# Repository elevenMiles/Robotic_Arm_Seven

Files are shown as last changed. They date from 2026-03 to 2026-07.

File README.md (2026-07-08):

---
# Supported by

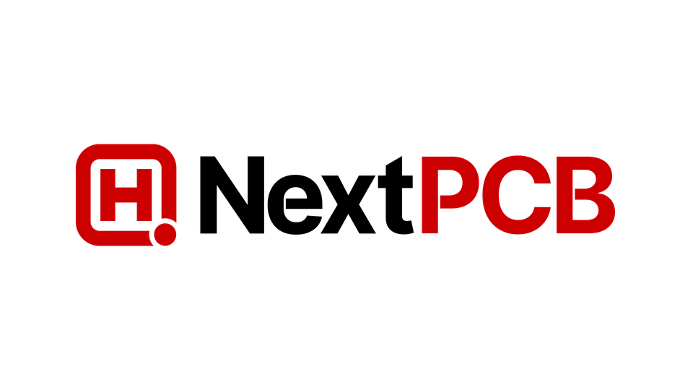
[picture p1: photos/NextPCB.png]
NextPCB


> Thanks to **NextPCB** for sponsoring this project with a financial grant – they're my first sponsor! If you ever need PCB or PCBA services, check them out using the link.
> -> https://www.nextpcb.com/?code=eleven

---

# Seven — 3-DOF Arduino Robotic Arm

> **⚠️ Safety Warning:** This project features a custom power supply setup. Please proceed at your own risk. I am not responsible for any damage to your components, your board, or yourself. Work carefully, and stay safe.

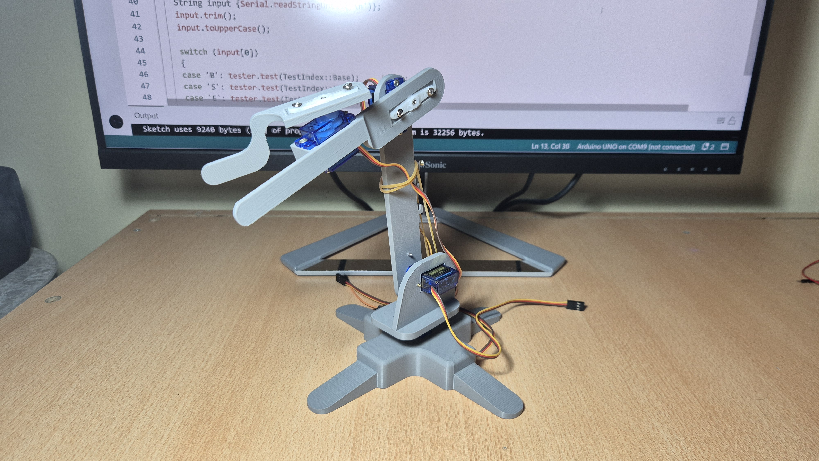
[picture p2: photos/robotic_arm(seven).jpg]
Seven Robotic Arm


A 3-DOF (Degrees of Freedom) robotic arm built with 3D-printed parts and SG90 servo motors, controlled via an Arduino Uno over serial communication. Seven supports **manual joint control**, **inverse kinematics**, **gripper control**, **waypoint list programming**, and **external software integration** via a handshake protocol.

---
Seven Robotic Arm Demo
---

## Assembly Guide

The assembly guide YouTube video is here: https://youtu.be/ZC04lUFtJYI?si=HDjUfc8iGIEtEkAY

---

## Table of Contents

- [Features](#features)
- [Hardware Requirements](#hardware-requirements)
- [3D Printing](#3d-printing)
- [Wiring & Circuit](#wiring--circuit)
- [Testing](#testing)
- [Software Setup](#software-setup)
- [Command Reference](#command-reference)
- [Calibration](#calibration)
- [Coordinate System](#coordinate-system)
- [Waypoint Lists](#waypoint-lists)
- [External Software Integration (Handshake)](#external-software-integration-handshake)
- [Project Structure](#project-structure)

---

## Features

- **Manual Control** — Set individual joint angles directly
- **Inverse Kinematics** — Move the end effector to any (X, Y, Z) coordinate in 3D space
- **Directional Movement** — Move up/down/left/right/forward/backward by a set amount in cm
- **Gripper Control** — Open/close gripper, with calibration for custom open/close angles
- **Waypoint Programming** — Record up to 25 positions and replay them in a loop
- **Handshake Protocol** — Integrate with external software by synchronizing over serial
- **EEPROM Calibration** — Calibration offsets persist across power cycles
- **Adjustable Speed** — Control angular speed between 30–90 degrees/second

---

## Hardware Requirements

Parts

| Component | Details |
|---|---|
| Arduino Uno | Or equivalent board |
| SG90 Servo Motor | × 4 |
| Large Breadboard | For power distribution |
| Jumper Wires | Male-to-Male |
| 2mm × 10mm Screws | For frame assembly |
| USB-A Cable (stripped) | Custom power delivery |
| USB-A to USB-C Adapter | For power supply connection |
| USB Wall Adapter | 5V DC, 3.0A minimum (see below) |

### Photos

<table>
  <tr>
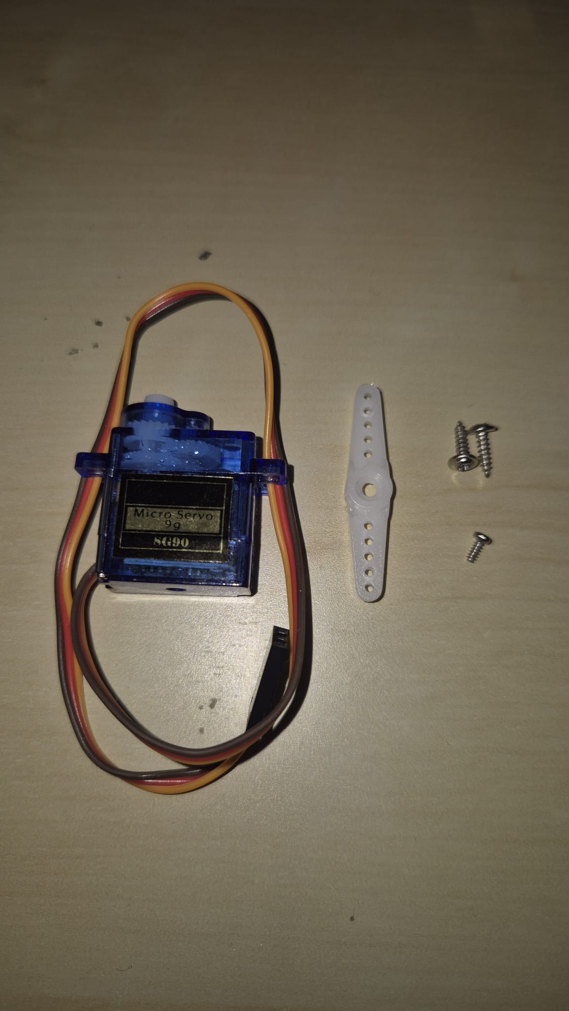
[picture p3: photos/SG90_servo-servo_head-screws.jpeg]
    <td align="center"><br/><sub>SG90 Servo + Screws</sub></td>
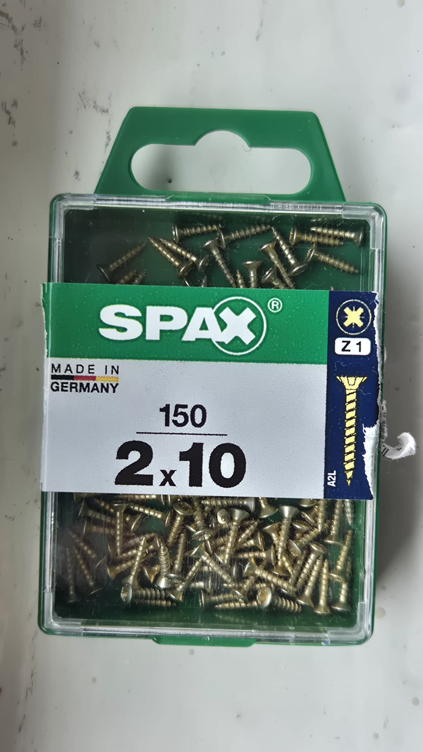
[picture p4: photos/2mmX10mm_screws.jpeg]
    <td align="center"><br/><sub>2mm × 10mm Frame Screws</sub></td>
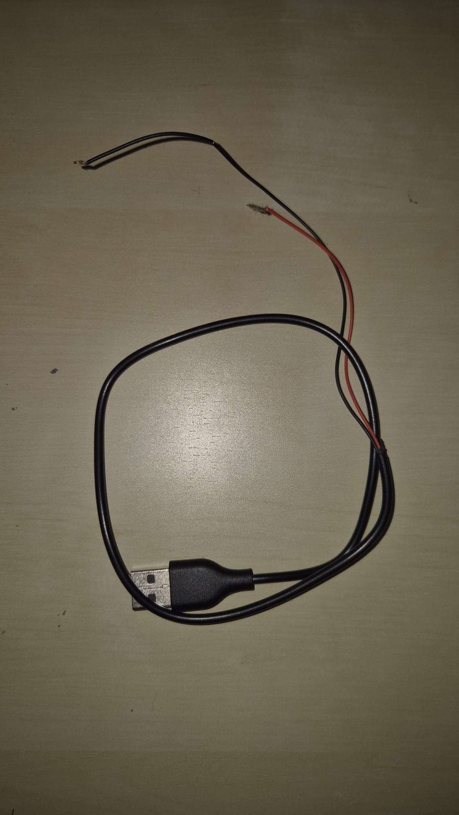
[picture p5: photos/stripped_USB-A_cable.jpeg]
    <td align="center"><br/><sub>Stripped USB-A Cable</sub></td>
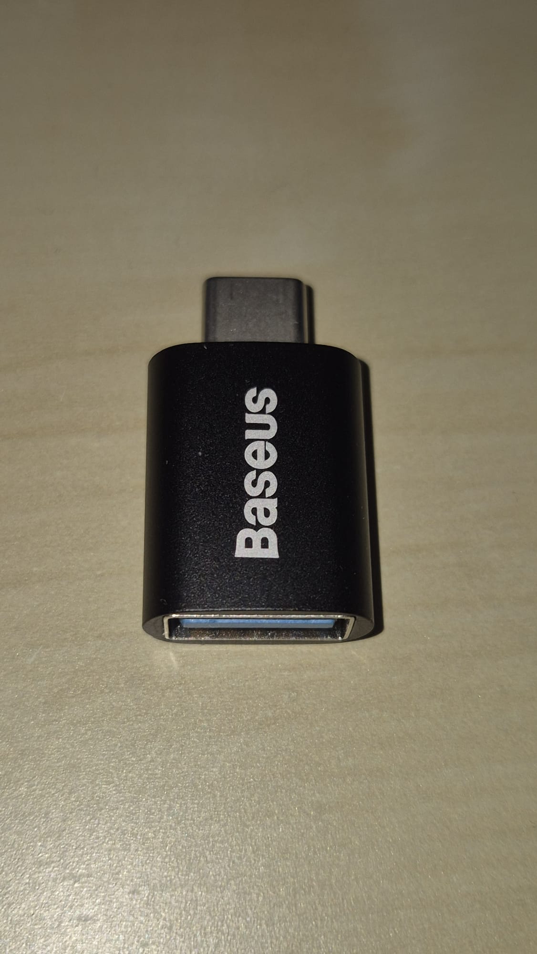
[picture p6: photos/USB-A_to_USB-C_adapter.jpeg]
    <td align="center"><br/><sub>USB-A to USB-C Adapter</sub></td>
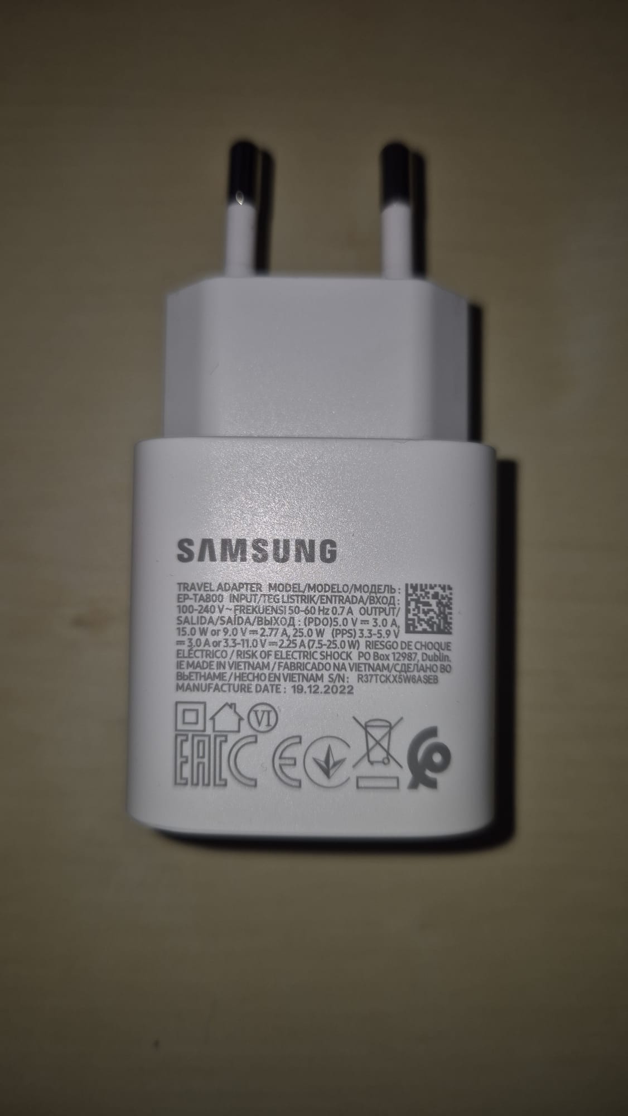
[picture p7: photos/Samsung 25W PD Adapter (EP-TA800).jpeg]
    <td align="center"><br/><sub>Samsung 25W PD Adapter</sub></td>
  </tr>
</table>

### Power Supply Notes

- **Voltage:** 5V DC (Stable)
- **Current:** 3.0A minimum (2.5A if running fewer servos)
- **Power Rating:** 15W – 25W
- **Recommended:** Samsung 25W PD Adapter (EP-TA800) or equivalent high-quality branded charger

> ⚠️ **Do not use cheap, unbranded "knock-off" adapters.** Quality adapters include Short Circuit Protection (SCP) and Overcurrent Protection (OCP), which are vital when using a custom-stripped USB cable.

> 💡 **Voltage Stability:** Ensure the adapter defaults to 5V. While many "Fast Chargers" can output 9V or 12V, they will only do so if they detect a compatible device. A basic stripped USB cable will naturally pull the default 5V, which is safe for SG90 servos.

> 🔌 **Common Ground:** You **must** connect the negative (GND) wire from the adapter to the Arduino GND pin to ensure a common reference point for control signals.

---

## 3D Printing

All STL files are in the `STL_files/` folder. **Recommended filament: Hyper PLA.**

| File | Supports | Infill |
|---|---|---|
| `base_large.stl` | Tree (auto) · Tree Hybrid · Top Z: 0.25 | Default |
| `base_slim.stl` | Tree (auto) · Tree Hybrid · Top Z: 0.25 | Default |
| `base_rotation.stl` | Tree (auto) · Default · Top Z: 0.25 | Default |
| `lower_arm.stl` | None | Gyroid |
| `upper_arm.stl` | Tree (auto) · Tree Hybrid · Top Z: 0.25 | Gyroid |
| `gripper_upper_arm.stl` | Tree (auto) · Tree Hybrid · Top Z: 0.25 | Gyroid |
| `gripper.stl` | Tree (auto) · Tree Hybrid · Top Z: 0.25 | Gyroid |

---

## Wiring & Circuit

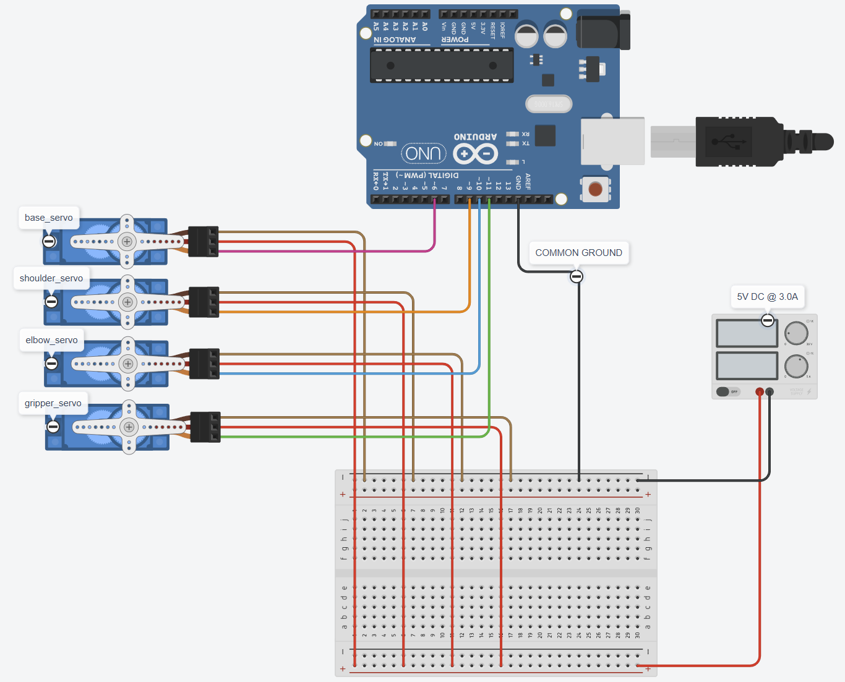
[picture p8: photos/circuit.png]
Circuit Diagram


| Servo | Arduino PWM Pin |
|---|---|
| Base | Digital Pin 6 |
| Shoulder | Digital Pin 9 |
| Elbow | Digital Pin 10 |
| Gripper | Digital Pin 11 |

- Servo **power (5V & GND)** wires are routed through the breadboard, which is powered by the external USB adapter.
- The USB adapter's **negative (GND) wire** must be connected to an **Arduino GND pin** to establish a common ground.
- Servo **signal wires** connect directly to the corresponding Arduino digital pins.

---

## Testing

A dedicated test sketch is provided in `code/test/test.ino` to help with servo assembly and verification.

**How to use:**

1. Upload `code/test/test.ino` to the Arduino.
2. Open the Serial Monitor at **115200 baud rate**.
3. Send one of the following characters to select a servo to test:

| Input | Servo |
|---|---|
| `B` | Base (Pin 6) |
| `S` | Shoulder (Pin 9) |
| `E` | Elbow (Pin 10) |
| `G` | Gripper (Pin 11) |

4. After selecting a servo, enter a numeric angle value (within that servo's min/max range) to move it.
5. When powered, every servo automatically center it to 90°.

---

## Software Setup

1. Open `code/main/main.ino` in the Arduino IDE.
2. Upload the sketch to your Arduino Uno.
3. Open the **Serial Monitor** at **115200 baud rate**.
4. Send commands as described in the [Command Reference](#command-reference) below.

### Configuration (`config.h`)

Key constants that govern the arm's behavior:

| Constant | Value | Description |
|---|---|---|
| `REST_ANGLE` | 90° | Default resting angle for all joints |
| `DEFAULT_ANGULAR_SPEED` | 60°/s | Default movement speed |
| `MIN_ANGULAR_SPEED` | 30°/s | Minimum allowed speed |
| `MAX_ANGULAR_SPEED` | 90°/s | Maximum allowed speed |
| `DEFAULT_MOVE_AMOUNT` | 5 cm | Default step for directional moves |
| `MAX_VECTOR_ARR_SIZE` | 25 | Maximum number of waypoints |
| `LENGTH_SHOULDER_ELBOW` | 12 cm | Upper arm segment length |
| `LENGTH_ELBOW_GRIPPER` | 12 cm | Forearm segment length |

> These are tuned for the default arm geometry. Only modify them if you alter the physical build.

---

## Command Reference

All commands are case-insensitive. Send them via the Serial Monitor at 115200 baud.

### Calibration Commands

| Command | Description |
|---|---|
| `-C` | Calibrate and save current angles to EEPROM |
| `-R` | Reset all calibration and gripper angles to 0 and save |
| `-GO(ANGLE)` | Set and save the gripper **open** angle (e.g. `-GO(45)`) |
| `-GC(ANGLE)` | Set and save the gripper **close** angle (e.g. `-GC(0)`) |

### Movement Commands

| Command | Description |
|---|---|
| `S(SPEED)` | Set angular speed in degrees/second (e.g. `S(75)`) |
| `A(X Y Z)` | **Inverse Kinematics** — move end effector to (X, Y, Z) in cm |
| `M(BASE SHOULDER ELBOW)` | **Manual** — set angles for each joint directly |
| `G(ANGLE)` | Set current gripper angle |
| `GO` | Open gripper |
| `GC` | Close gripper |
| `O` | Reset arm to rest position (90°, 90°, 90°) |

### Directional Movement

Move the end effector in 3D space by a given distance in cm. Omitting the amount moves by the default 5 cm.

| Command | Description |
|---|---|
| `U(x)` / `U` | Move **up** x cm (default 5 cm) |
| `D(x)` / `D` | Move **down** x cm |
| `L(x)` / `L` | Move **left** x cm |
| `R(x)` / `R` | Move **right** x cm |
| `F(x)` / `F` | Move **forward** x cm |
| `B(x)` / `B` | Move **backward** x cm |

### Waypoint List Commands

| Command | Description |
|---|---|
| `+S` | Create a new list and save current position as the **start point** |
| `+W` | Save current position and gripper state as a **waypoint** |
| `+E` | Save current position as the **end point** and close the list |
| `+M` | **Begin looping** through the waypoint list |

### Handshake Commands

| Command | Description |
|---|---|
| `HA` | Activate handshake mode |
| `HD` | Deactivate handshake mode |

---

## Calibration

Due to physical mounting variation, servo joints may not align perfectly at their true 90° position. Calibration corrects this offset and stores it to EEPROM so it persists across power cycles.

**How to calibrate:**

1. Use the `M(BASE SHOULDER ELBOW)` command to manually adjust each joint until each one points exactly at its physical 90° rest position.
2. Once satisfied, send `-C` to save the calibration to EEPROM.

**Gripper calibration:**

1. Use `G(ANGLE)` to find a good open angle (typically ~45°) and close angle (typically ~0°).
2. Save them with `-GO(45)` and `-GC(0)`.

**Reset calibration:**

Send `-R` to wipe all calibration values (joints and gripper) back to zero.

---

## Coordinate System

The **shoulder servo's pivot point** is the origin `(0, 0, 0)`. All coordinates are in centimeters.

| Axis | Direction |
|---|---|
| X | Forward |
| Y | Left / Right |
| Z | Up / Down |

**Example:** `A(10 0 5)` moves the gripper to a point 10 cm forward and 5 cm up from the shoulder pivot.

**Reach limits:**
- Minimum X: 1 cm
- Minimum Z: −6 cm
- Maximum reach: ~24 cm (sum of both arm segments)

---

## Waypoint Lists

Waypoints let you record a sequence of positions and replay them continuously in a loop. The list can hold up to **25 waypoints**.

**Workflow (always in this order):**

```
+S  →  (move arm)  →  +W  →  (move arm)  →  +W  →  ...  →  +E  →  +M
```

1. Send `+S` to start a new list and record the current position as the start.
2. Move the arm to the next desired position, then send `+W` to record it as a waypoint.
3. Repeat step 2 for as many waypoints as needed (up to 25).
4. Send `+E` to record the final end position and close the list.
5. Send `+M` to start looping through the list.

> **Note:** All serial commands are blocked while the arm is executing a waypoint list. Waypoint commands (`+S`, `+W`, `+E`, `+M`) and calibration (`-C`) are disabled while handshake is active.

---

## External Software Integration (Handshake)

Seven can be controlled from any external application over serial.

- Send `HA` to activate handshake mode.
- In handshake mode, the Arduino prints `"K"` to the serial port after every update cycle.
- Your application should wait for `"K"` before sending the next command — this ensures commands are processed in sync with the arm's update loop.
- Send `HD` to deactivate handshake mode.

> While handshake is active, calibration (`-C`) and waypoint list commands (`+S`, `+W`, `+E`, `+M`) are disabled.

---

## Project Structure

```
seven_github/
├── code/
│   ├── main/
│   │   ├── main.ino            # Main Arduino sketch
│   │   ├── roboticArm.h/.cpp   # Core arm logic, IK, commands, EEPROM
│   │   ├── servoConfig.h/.cpp  # Servo wrapper with rotation direction & limits
│   │   ├── vector3.h/.cpp      # 3D vector math (magnitude, normalize, distance)
│   │   ├── fixedVector.h       # Fixed-size array for waypoint storage
│   │   └── config.h            # Global constants (speeds, angles, limits)
│   └── test/
│       ├── test.ino            # Servo testing sketch
│       ├── roboticArmTester.h  # Tester class header
│       ├── roboticArmTest.cpp  # Tester class implementation
│       ├── servoConfig.h/.cpp  # Servo config for test environment
│       └── config.h            # Constants for test environment
├── STL_files/
│   ├── base_large.stl
│   ├── base_slim.stl
│   ├── base_rotation.stl
│   ├── lower_arm.stl
│   ├── upper_arm.stl
│   ├── gripper_upper_arm.stl
│   └── gripper.stl
└── photos/
    ├── robotic_arm(seven).jpg
    ├── circuit.png
    ├── parts.png
    └── ...
```

---

*Author: T. Selçuk Yüksel*

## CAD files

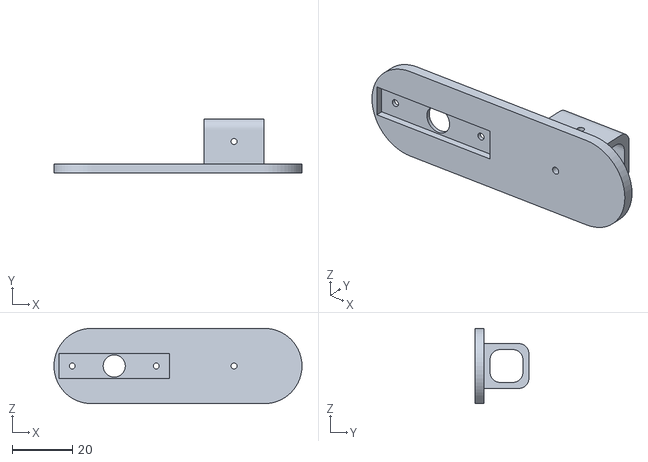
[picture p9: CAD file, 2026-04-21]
STL_files/pen_holder_slim.stl
82.7 x 18.0 x 25.1

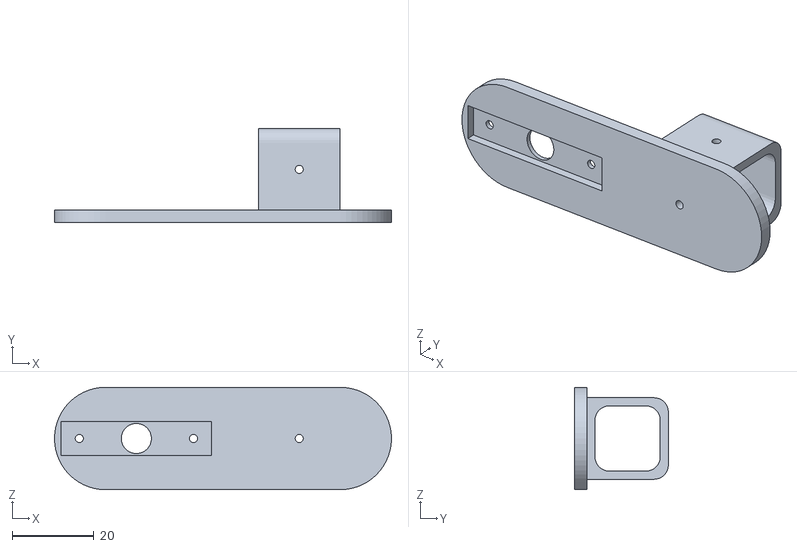
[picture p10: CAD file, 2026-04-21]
STL_files/pen_holder_large.stl
82.7 x 23.0 x 25.1

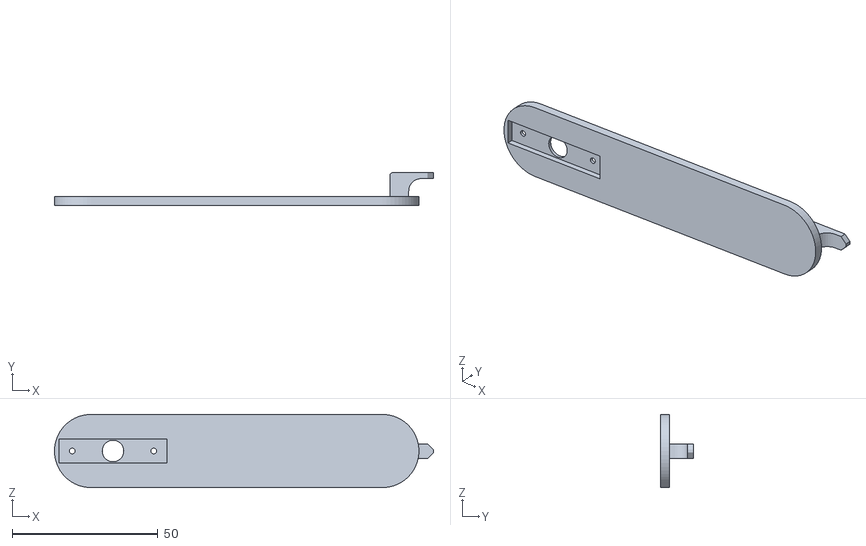
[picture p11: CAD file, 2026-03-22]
STL_files/upper_arm.stl
130.1 x 11.2 x 25.1

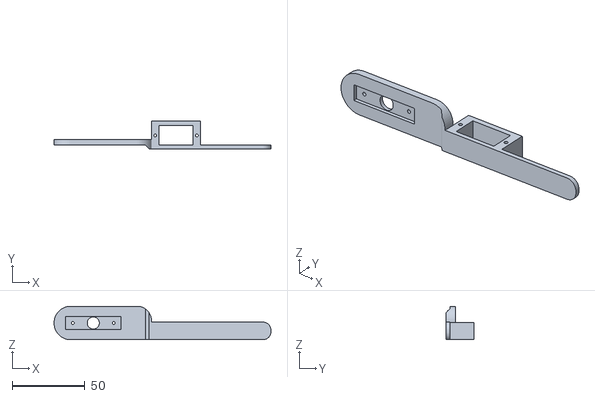
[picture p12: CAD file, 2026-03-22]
STL_files/gripper_upper_arm.stl
149.0 x 19.0 x 23.0

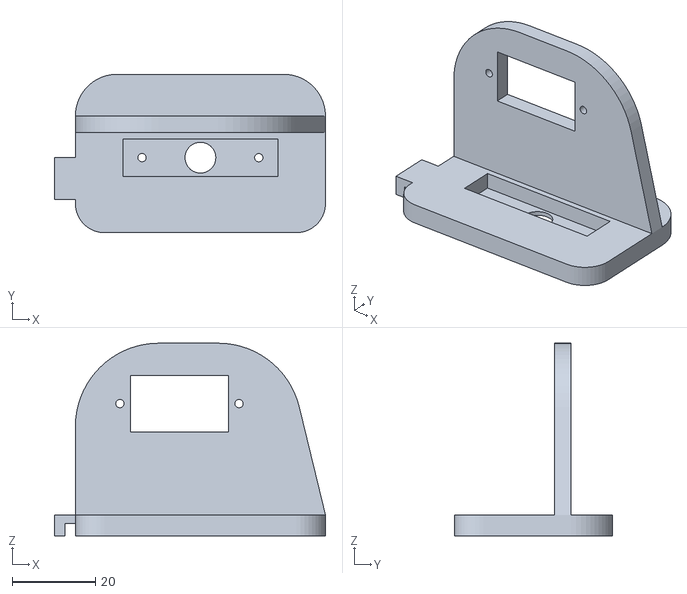
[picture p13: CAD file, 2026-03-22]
STL_files/base_rotation.stl
65.0 x 38.0 x 46.2

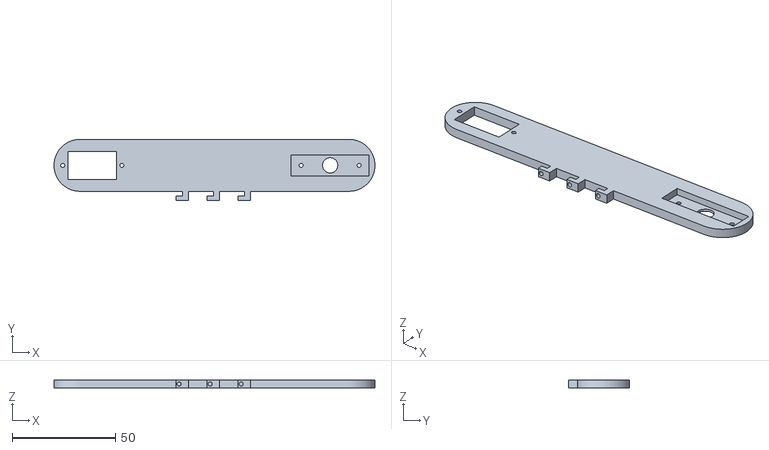
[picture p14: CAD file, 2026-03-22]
STL_files/lower_arm.stl
155.2 x 29.6 x 4.00

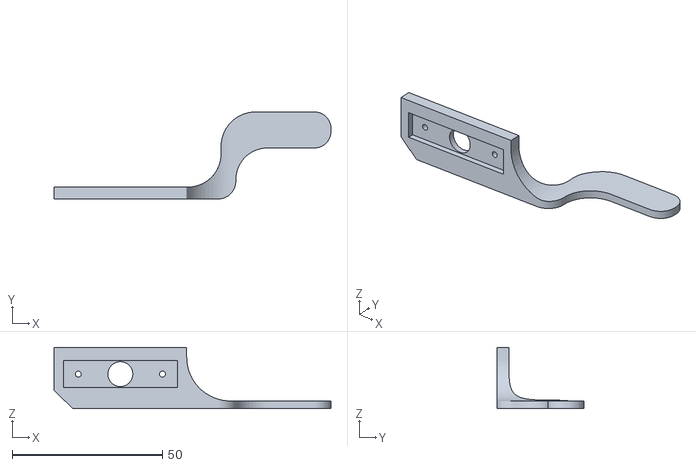
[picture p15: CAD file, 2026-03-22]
STL_files/gripper.stl
92.2 x 29.0 x 20.4

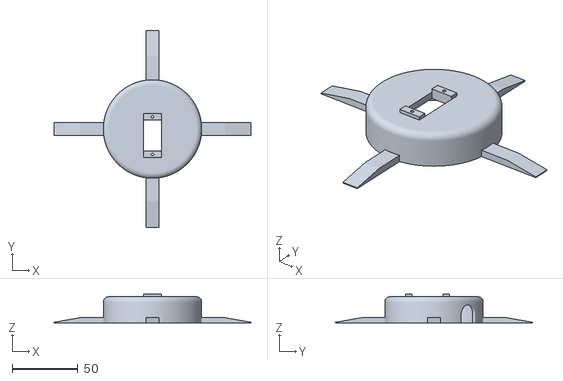
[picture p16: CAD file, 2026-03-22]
STL_files/base_slim.stl
150.0 x 150.0 x 22.0

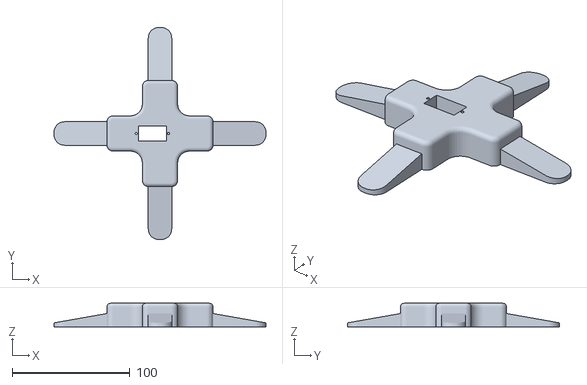
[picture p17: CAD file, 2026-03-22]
STL_files/base_large.stl
180.0 x 180.0 x 20.0

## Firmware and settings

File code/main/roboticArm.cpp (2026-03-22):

#include "HardwareSerial.h"
#include "WString.h"
#include "config.h"
#include "fixedVector.h"
#include "vector3.h"
#include "servoConfig.h"
#include "roboticArm.h"
#include <math.h>
#include <EEPROM.h>
#include <Arduino.h>

struct Calibration
{
  float baseAngle;
  float shoulderAngle;
  float elbowAngle;
  float gripperOpenAngle;
  float gripperCloseAngle;
};

RoboticArm::RoboticArm(
    float _lengthShoulderElbow, 
    float _lengthElbowGripper, 
    ServoConfig _baseServo, 
    ServoConfig _shoulderServo,
    ServoConfig _elbowServo,
    ServoConfig _gripperServo
  )
  : length_shoulder_elbow {_lengthShoulderElbow}, 
    length_elbow_gripper {_lengthElbowGripper},

    base_servo {_baseServo},
    shoulder_servo {_shoulderServo},
    elbow_servo {_elbowServo},
    gripper_servo {_gripperServo}
{
}

void RoboticArm::begin()
{
  getEEPROM();

  base_servo.begin(static_cast<int>(Config::REST_ANGLE + calib_base_angle));
  shoulder_servo.begin(static_cast<int>(Config::REST_ANGLE + calib_shoulder_angle));
  elbow_servo.begin(static_cast<int>(Config::REST_ANGLE + calib_elbow_angle));
  
  gripper_servo.begin(static_cast<int>(gripper_open_angle));

  min_distance = abs(length_shoulder_elbow - length_elbow_gripper) + Config::MIN_SAFETY_MARGIN;
  max_distance = length_shoulder_elbow + length_elbow_gripper      - Config::MAX_SAFETY_MARGIN;
  target_gripper_angle = gripper_open_angle;

  Serial.println(F("Robotic arm initialized.")); 
  Serial.println(F("If this is the first run, please use -R command to reset all calibration angles."));
}

void RoboticArm::update(float delta_time)
{
  float max_delta {angular_speed * delta_time};

  // ------------------------------------------------------------------------------
  // GRIPPER UPDATE
  float distance {abs(target_gripper_angle - current_gripper_angle)};

  if (max_delta > distance)
  {
    current_gripper_angle = target_gripper_angle;
  }
  else
  {
    float direction {(target_gripper_angle - current_gripper_angle) / distance};
    current_gripper_angle += direction * max_delta;
  }

  if (abs(current_gripper_angle - gripper_close_angle) < max_delta)
  {
    gripperState = close;
  }
  else if (abs(current_gripper_angle - gripper_open_angle) < max_delta)
  {
    gripperState = open;
  }

  // ------------------------------------------------------------------------------
  // ARM UPDATE
  Vector3 calibration_angle_vector {calib_base_angle, calib_shoulder_angle, calib_elbow_angle};

  Vector3 current_angle_vector {current_base_angle, current_shoulder_angle, current_elbow_angle};
  Vector3 target_angle_vector  {target_base_angle, target_shoulder_angle, target_elbow_angle};

  Vector3 movement = Vector3::moveTowards(current_angle_vector, target_angle_vector + calibration_angle_vector, max_delta);

  current_base_angle = movement.x;
  current_shoulder_angle = movement.y;
  current_elbow_angle = movement.z;

  // ------------------------------------------------------------------------------
  if (list_move)
  {
    if (set_timer)
    {
      set_timer = false;
      if (counter == 0)
      {
        inverseKinematics(waypointList[waypoint_index].position);
        Vector3 current_angle_vector {current_base_angle, current_shoulder_angle, current_elbow_angle};
        Vector3 target_angle_vector  {target_base_angle, target_shoulder_angle, target_elbow_angle};
        float dist {Vector3::distance(current_angle_vector, target_angle_vector)};
        timer = dist / angular_speed + Config::PAUSE_TIME;
      }
      if (counter == 1)
      {
        setGripper(waypointList[waypoint_index].gripper);
        float dist {abs(current_gripper_angle - target_gripper_angle)};
        timer = dist / angular_speed + Config::PAUSE_TIME;
      }

      counter += 1;
      if (counter > 1)
      {
        counter = 0;
        waypoint_index += 1;
      }
    }

    timer -= delta_time;
    if (timer <= 0.0f)
    {
      set_timer = true;
      if (waypoint_index >= waypointList.len())
      {
        endMoveOnWaypoints();
      }
    }
  }
  // ------------------------------------------------------------------------------
  // WRITE TO SERVOS
  base_servo.write(static_cast<int>(current_base_angle));
  shoulder_servo.write(static_cast<int>(current_shoulder_angle));
  elbow_servo.write(static_cast<int>(current_elbow_angle));
  gripper_servo.write(static_cast<int>(current_gripper_angle));
  // ------------------------------------------------------------------------------
  
  // HANDSHAKE
  if (handshake)
    Serial.println(F("K"));
}

void RoboticArm::command(char* cmd)
{
  // 0. No command accepted during waypoint list movement.
  if (list_move) return;

  // 1. Skip any leading whitespace or newlines
  while (*cmd == ' ' || *cmd == '\n' || *cmd == '\r' || *cmd == '\t') 
  {
    cmd++;
  }

  // 2. Check if the string is empty after trimming
  if (cmd[0] == '\0') 
  {
    return; 
  }

  if (handshake)
  {
    switch(cmd[0])
    {
    case '-':
    case '+': return;
    }
  }

  // 3. Process the command
  switch(cmd[0])
  {
    case '-': calibrationCommand(cmd); return;
    case 'H': handshakeCommand(cmd);   return;
    case 'S': speedCommand(cmd);       return;
    case 'A': automaticCommand(cmd);   return;
    case 'M': manualCommand(cmd);      return;
    case 'G': gripperCommand(cmd);     return;
    case 'O': resetArm();              return;
    case 'U':
    case 'D':
    case 'L':
    case 'R':
    case 'F':
    case 'B': moveCommand(cmd);        return; 
    case '+': listCommand(cmd);        return;
    case 'T': Serial.print(F("End effector position: ")); forwardKinematics().println(); return;
  }
  
  Serial.print(F("INVALID COMMAND: "));
  Serial.println(cmd[0]); // Print the character that failed for debugging
}

void RoboticArm::calibrationCommand(char* cmd)
{
  switch (cmd[1])
  {
  case 'C': calibrateAndSave();    return;
  case 'R': resetAllCalibration(); return;
  case 'G': saveGripper(cmd);      return;
  }
}

void RoboticArm::calibrateAndSave()
{
  calib_base_angle = current_base_angle - Config::REST_ANGLE;
  calib_shoulder_angle = current_shoulder_angle - Config::REST_ANGLE;
  calib_elbow_angle = current_elbow_angle - Config::REST_ANGLE;

  saveEEPROM();

  // Move robotic arm to it's rest position after calibration.
  target_base_angle = Config::REST_ANGLE;
  target_shoulder_angle = Config::REST_ANGLE;
  target_elbow_angle = Config::REST_ANGLE;

  Serial.println(F("CALIBRATED AND SAVED."));
}

void RoboticArm::resetAllCalibration()
{
  calib_base_angle = 0.0f;
  calib_shoulder_angle = 0.0f;
  calib_elbow_angle = 0.0f;
  gripper_open_angle = gripper_servo.getMaxAngle();
  gripper_close_angle = gripper_servo.getMinAngle();
  
  saveEEPROM();

  Serial.println(F("ALL CALIBRATION VALUES RESET AND SAVED."));
}

void  RoboticArm::handshakeCommand(char* cmd)
{
  switch (cmd[1]) 
  {
  case 'A': handshake = true; return;
  case 'D': handshake = false; return;
  }
}
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

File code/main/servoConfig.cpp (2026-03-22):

#include "config.h"
#include "servoConfig.h"
#include <Servo.h>
#include <Arduino.h>

ServoConfig::ServoConfig(int _pin, ServoRot _rot, int _minAngle, int _maxAngle)
  : pin {_pin},
    rot {_rot},
    min_angle {_minAngle},
    max_angle {_maxAngle}
{
}

void ServoConfig::begin(int angle)
{
  // Tell the Servo library what the angle should be 
  // BEFORE the signal pin actually starts sending pulses.
  servoObj.write(angle); // Or your specific REST_ANGLE
  servoObj.attach(pin);
}

void ServoConfig::write(int angle)
{
  int safe_angle {constrain(angle, min_angle, max_angle)};
  switch (rot)
  {
  case ServoRot::Normal:
    servoObj.write(constrain(safe_angle, 0, 180));
    return;
  case ServoRot::Reverse:
    servoObj.write(constrain(180 - safe_angle, 0, 180)); 
    return;
  }
}

int ServoConfig::getMinAngle() const
{
  return min_angle;
}

int ServoConfig::getMaxAngle() const
{
  return max_angle;
}

int ServoConfig::getPin() const
{
  return pin;
}

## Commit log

2026-03-22 Add assembly guide to README
    Added an assembly guide section with a video link.
2026-03-22 Modify assembly guide to include YouTube link
    Updated the assembly guide section to include a direct link.
2026-03-23 Include demo image in README
    Added demo image for the Seven Robotic Arm.
